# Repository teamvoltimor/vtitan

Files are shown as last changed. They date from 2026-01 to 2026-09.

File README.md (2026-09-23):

# Team Voltimor

> [!NOTE]
> Este repositorio corresponde a nuestra participación en la World Robot Olympiad 2026 con vTitan. Si buscas información sobre nuestra participación en la World Robot Olympiad 2025 con Klevor, el robot del Team Steel Bot, visita el repositorio [**klevor**](https://github.com/teamsteelbot/klevor).

> 🕊️ Este proyecto está dedicado a la memoria de **Javier Pérez** ([@kaucrow](https://github.com/kaucrow)), amigo y colega, y de **Luna Margarita**, compañera de doce años. La [dedicatoria completa](memorial.md) vive en [`memorial.md`](memorial.md).

<p align="center">
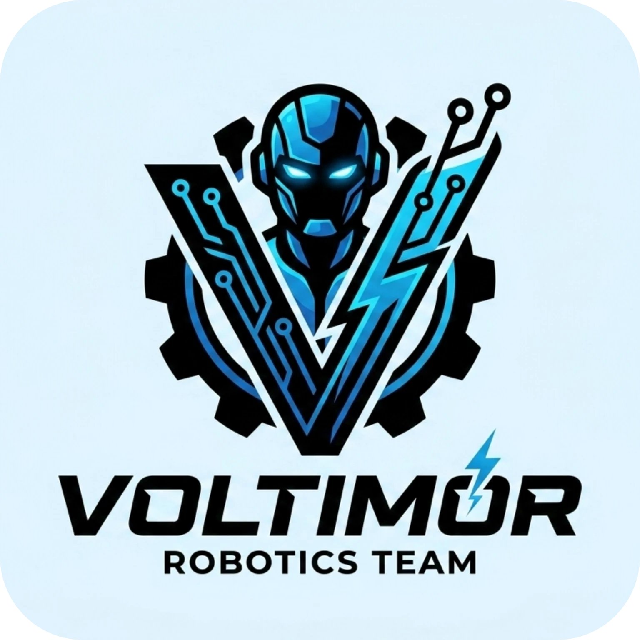
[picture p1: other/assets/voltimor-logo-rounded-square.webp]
Logo del Team Voltimor
    
    <br>
    <i>Logo del Equipo</i>
</p>

Bienvenidos al repositorio de vTitan, el robot del Team Voltimor, que compite en la World Robot Olympiad 2026 en la categoría Futuros Ingenieros. Aquí encontrarás toda la información sobre el robot, incluyendo su código, modelos 3D, esquemas y documentación.

<p align="center">
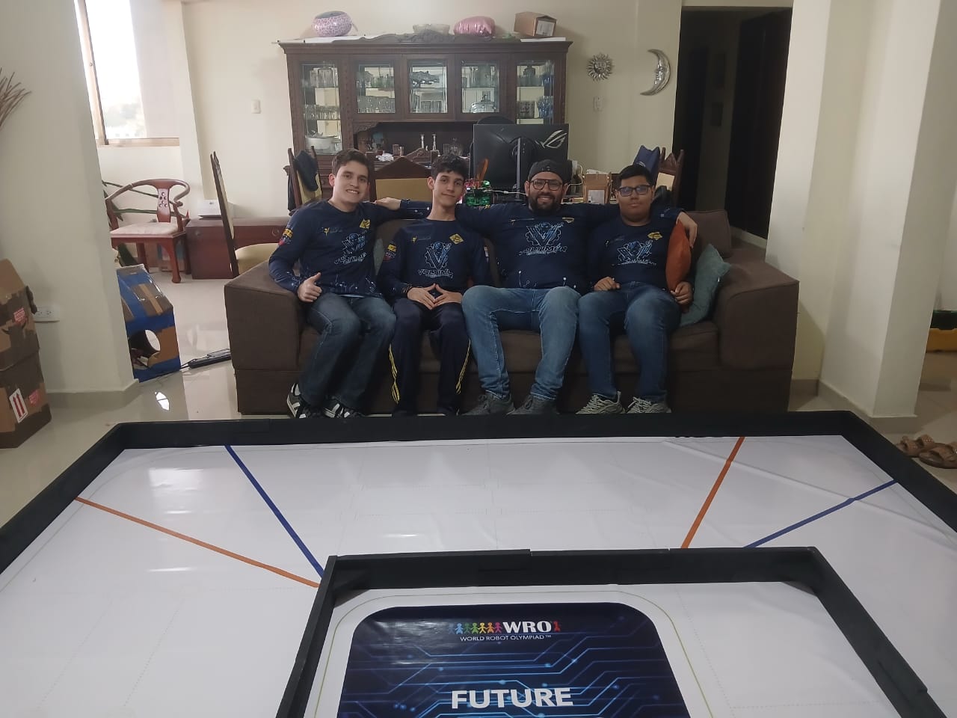
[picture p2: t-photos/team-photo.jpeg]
El equipo de Voltimor con vTitan
    
    <br>
    <i>Foto del Equipo, de izquierda a derecha: Ramón Álvarez, Sebastián Álvarez, Jesús Pérez (Padre, Mentor), Jesús Pérez</i>
</p>

El equipo lo forman tres miembros:

- **Ramón Álvarez**, 20 años. [ralvarezdev](https://github.com/ralvarezdev). Líder del equipo y encargado de la programación. Trabaja en Automation Labs y finalizó sus estudios de Ingeniería en Computación en URU.
- **Sebastián Álvarez**, 16 años. [salvarezdev](https://github.com/salvarezdev). Encargado de la programación, la documentación y las decisiones sobre la lógica del robot. Cursa el primer trimestre de Ingeniería en Computación en URU.
- **Jesús Pérez**, 16 años. [JesusPerez15](https://github.com/JesusPerez15). Encargado del diseño, la mecánica y la fabricación del robot. Cursa quinto año de bachillerato en el Colegio Salto Ángel.

## vTitan en números

<table align="center">
<thead>
<tr>
<th align="left">Métrica</th>
<th align="left">Valor</th>
<th align="left">Contexto</th>
</tr>
</thead>
<tbody>
<tr>
<td align="left">Detección de señales</td>
<td align="left"><strong>15 Hz</strong> punta a punta</td>
<td align="left">Captura 640x640 + inferencia NPU + publicación; 101.5 FPS el modelo solo</td>
</tr>
<tr>
<td align="left">Corpus de simulación</td>
<td align="left"><strong>638 / 640</strong> escenarios Open</td>
<td align="left">Semilla fija y resultados repetibles; los 2 casos restantes identificados uno por uno</td>
</tr>
<tr>
<td align="left">Peso del robot</td>
<td align="left"><strong>~1460 g</strong></td>
<td align="left">Límite reglamentario 1500 g, con ~40 g de margen</td>
</tr>
<tr>
<td align="left">Techo de velocidad real</td>
<td align="left"><strong>~0.58 m/s</strong></td>
<td align="left">Descubierto al corregir un error de cuantización que lo limitaba a 0.45 m/s</td>
</tr>
<tr>
<td align="left">Duración de una ronda</td>
<td align="left"><strong>180 s</strong> sin pausa</td>
<td align="left">Por eso todo lo que ocurre a bordo queda grabado en bags MCAP</td>
</tr>
<tr>
<td align="left">Lazo de velocidad en pista</td>
<td align="left"><strong>~2% de error</strong> de seguimiento</td>
<td align="left">Tres vueltas limpias en 132.5 s frente a 142.3 s antes del ajuste</td>
</tr>
</tbody>
</table>

Cada número es medido, no estimado, y puede rastrearse hasta el código y la medición que lo produjo vía el historial de git (ver [Versionado](#versionado)).

**Índice**

1. **[vTitan en números](#vtitan-en-números)**
2. **[Estructura del repositorio](#estructura-del-repositorio)**
    1. [Cómo explorar este repositorio](#cómo-explorar-este-repositorio)
3. **[Arranque rápido y reproducibilidad](#arranque-rápido-y-reproducibilidad)**
    1. [Requisitos previos](#requisitos-previos-una-sola-vez)
    2. [Desarrollo y simulación](#desarrollo-y-simulación-en-el-computador-de-desarrollo)
    3. [Despliegue al robot](#despliegue-al-robot-desde-el-computador-por-ssh)
    4. [Operación en pista](#operación-en-pista-directamente-en-la-raspberry-pi-5-vía-ssh)
    5. [Provisionado desde cero](#provisionado-desde-cero-instalar-el-sistema-en-las-raspberry-pi)
    6. [Documentación](#documentación)
    7. [Pruebas](#pruebas)
    8. [Versionado](#versionado)
4. **[Historial del equipo](#historial-del-equipo)**
    1. [Klevor (WRO 2025)](#klevor-wro-2025)
        1. [Klevor v0.1](other/docs/development/previous-prototypes/klevor-v0.1.md)
        2. [Klevor v0.1.1](other/docs/development/previous-prototypes/klevor-v0.1.1.md)
        3. [Klevor v0.2](other/docs/development/previous-prototypes/klevor-v0.2.md)
        4. [Klevor v1.0](other/docs/development/previous-prototypes/klevor-v1.0.md)
    2. [vTitan (WRO 2026)](#vtitan-wro-2026)
5. **[Movilidad y diseño mecánico](#movilidad-y-diseño-mecánico)**
    1. [Restricciones iniciales](#restricciones-iniciales)
    2. [Métodos de prototipaje](#métodos-de-prototipaje)
    3. [Evolución y justificación del diseño](#evolución-y-justificación-del-diseño)
        1. [Fase 1: prototipo de rin estático, corona interna y guayas flexibles](#fase-1-prototipo-de-rin-estático-corona-interna-y-guayas-flexibles)
        2. [Fase 2: pruebas de integración y detección de fallas](#fase-2-pruebas-de-integración-y-detección-de-fallas)
        3. [Fase 3: rediseño a engranajes perpendiculares, coronas y correa dentada](#fase-3-rediseño-a-engranajes-perpendiculares-coronas-y-correa-dentada)
        4. [Fase 4: optimización de peso, integración y chasis final](#fase-4-optimización-de-peso-integración-y-chasis-final)
        5. [Fase 5: integración del REV HD Hex Motor](#fase-5-integración-del-rev-hd-hex-motor)
    4. [Sistema de transmisión](#sistema-de-transmisión)
    5. [Sistema de dirección](#sistema-de-dirección)
    6. [Estructura mecánica](#estructura-mecánica)
        1. [Chasis inferior](#chasis-inferior)
        2. [Monochasis](#monochasis)
    7. [Montaje](#montaje)
        1. [Las piezas, y cómo mirarlas](#las-piezas-y-cómo-mirarlas)
    8. [Relación de torque y velocidad](#relación-de-torque-y-velocidad)
        1. [Velocidad: teórica contra real](#velocidad-teórica-contra-real)
6. **[Arquitectura de energía y sensores](#arquitectura-de-energía-y-sensores)**
    1. [Lista de componentes](#lista-de-componentes)
        1. [Raspberry Pi 5 (16 GB de RAM)](#raspberry-pi-5-16-gb-de-ram)
        2. [Raspberry Pi Camera Module 3 Wide](#raspberry-pi-camera-module-3-wide)
        3. [Raspberry Pi AI HAT+ (26 TOPS)](#raspberry-pi-ai-hat-26-tops)
        4. [Raspberry Pi Zero 2 W](#raspberry-pi-zero-2-w)
        5. [RPLiDAR C1](#rplidar-c1)
        6. [Servomotor Hiwonder HPS-3527SG (35 kg·cm)](#servomotor-hiwonder-hps-3527sg-35-kgcm)
        7. [REV HD Hex Motor](#rev-hd-hex-motor)
        8. [IMU GY-BNO085](#imu-gy-bno085)
        9. [Batería Li-Po Ovonic Air de 11.1 V](#batería-li-po-ovonic-air-de-111-v)
        10. [Puente H BTS7960 / IBT-2](#puente-h-bts7960--ibt-2)
        11. [Step Down Mini-560 Pro](#step-down-mini-560-pro)
        12. [Pantalla OLED SSD1306](#pantalla-oled-ssd1306)
        13. [Convertidor KL89576 (DC a USB-C)](#convertidor-kl89576-dc-a-usb-c)
    2. [Diagrama de conexiones](#diagrama-de-conexiones)
    3. [Consumo energético](#consumo-energético)
    4. [Calibración](#calibración)
7. **[Arquitectura de software](#arquitectura-de-software)**
    1. [Arquitectura ROS2 y reparto entre dos computadores](#arquitectura-ros2-y-reparto-entre-dos-computadores)
        1. [La pantalla OLED, el único instrumento en pista](#la-pantalla-oled-el-único-instrumento-en-pista)
        2. [La segunda pila (stack) en Go, y por qué no corre en carrera](#la-segunda-pila-stack-en-go-y-por-qué-no-corre-en-carrera)
    2. [Modelo de detección YOLO](#modelo-de-detección-yolo)
        1. [El modelo y su cadena de procesamiento](#el-modelo-y-su-cadena-de-procesamiento)
        2. [Datos de entrenamiento](#datos-de-entrenamiento)
        3. [Cómo lo medimos (y qué cambió por eso)](#cómo-lo-medimos-y-qué-cambió-por-eso)
        4. [Qué pasa cuando la visión falla](#qué-pasa-cuando-la-visión-falla)
    3. [Algoritmo PID](#algoritmo-pid)
        1. [Control de velocidad: PI sobre RPM](#control-de-velocidad-pi-sobre-rpm)
        2. [Dirección: de PID a pure pursuit](#dirección-de-pid-a-pure-pursuit)
        3. [El modo ciego: P de centrado eliminada por medición](#el-modo-ciego-p-de-centrado-eliminada-por-medición)
        4. [El rol del giroscopio](#el-rol-del-giroscopio)
8. **[Estrategia en pista](#estrategia-en-pista)**
    1. [Inferencia del sentido de la vuelta](#inferencia-del-sentido-de-la-vuelta)
    2. [Seguimiento de pasillo, vueltas y escapes](#seguimiento-de-pasillo-vueltas-y-escapes)
    3. [Vista completa de cada desafío](#vista-completa-de-cada-desafío)
9. **[Análisis y simulación](#análisis-y-simulación)**
    1. [Grabación y análisis de carreras](#grabación-y-análisis-de-carreras)
    2. [Simulador y corpus de escenarios](#simulador-y-corpus-de-escenarios)
10. **[Pensamiento sistémico y decisiones de ingeniería](#pensamiento-sistémico-y-decisiones-de-ingeniería)**
    1. [Interacciones entre subsistemas](#interacciones-entre-subsistemas)
    2. [Diseño gobernado por configuración](#diseño-gobernado-por-configuración)
    3. [Perfiles de hardware intercambiables](#perfiles-de-hardware-intercambiables)
    4. [Compensaciones y alternativas descartadas](#compensaciones-y-alternativas-descartadas)
    5. [Registro de decisiones de arquitectura (ADR)](#registro-de-decisiones-de-arquitectura-adr)
    6. [Ciclo de trabajo: idea → simulación → pista](#ciclo-de-trabajo-idea--simulación--pista)
    7. [Hallazgos de ingeniería](#hallazgos-de-ingeniería)
    8. [Gestión de riesgos](#gestión-de-riesgos)
    9. [Tecnologías utilizadas](#tecnologías-utilizadas)
11. **[Videos de vTitan](#videos-de-vtitan)**
    1. [Open Challenge](#open-challenge)
    2. [Open Challenge Simulation](#open-challenge-simulation)
    3. [Obstacle Challenge Simulation](#obstacle-challenge-simulation)
    4. [Parking Challenge](#parking-challenge)
    5. [Otros](#otros)

## Estructura del repositorio

La raíz del repositorio sigue la estructura que pide la categoría Futuros Ingenieros de la WRO. Cada carpeta obligatoria está en su sitio, y las que apuntan a un monorepo más grande llevan su propio `README.md` con la ruta exacta:

```text
vtitan/
├── README.md          # Este documento: la documentación completa de ingeniería
├── CHANGELOG.md       # Notas de versión de v1.0, v1.1 y v1.2
├── t-photos/          # Fotos del equipo
├── v-photos/          # Fotos de vTitan y de los prototipos anteriores
├── video/             # Enlaces a los videos de las rondas (video/video.md)
├── schemes/           # Diagramas de flujo y esquemático de conexiones
│   ├── flowcharts/    #   Fuentes Mermaid + renders WebP: common/, open/, obstacles/
│   └── wiring/        #   Esquemático del arnés + proyecto tscircuit que lo genera
├── models/            # Modelos 3D (ver models/README.md)
│   ├── vtitan/      #   WRO 2026: blueprints/, step-files/ (CAD), stl-files/ (visor 3D)
│   └── klevor/      #   WRO 2025: el prototipo de la temporada anterior
├── src/               # python/ (pila ROS2), go/ (reimplementación Go), config/ (TOML
│                      #   compartido, leído por ambos), model/ (esquemas JSON que
│                      #   validan ese TOML), tools/ y assets/ (imágenes compartidas)
├── other/             # Todo lo que no es material de competencia
│   ├── apps/          #   backend/, frontend/, gazebo/, auto-annotator/, hugo-docs/, landing/
│   ├── assets/        #   Logos e imágenes de esta documentación
│   ├── contracts/     #   proto/ (buf, esquemas gRPC/NATS) y openapi/ (spec-first REST)
│   ├── data/          #   Salidas de ejecución (bags, fotos, videos); vacía en el repo
│   ├── deploy/ansible/#   Provisionamiento de las placas (tareas task rpi:*, windows:*)
│   ├── docs/          #   Bitácora, referencia de configuración, datasheets, prototipos
│   ├── ml/hailo/ ml/weights/  # Entrenamiento del detector y pesos publicados
│   ├── scripts/       #   Utilidades de desarrollo (configuración de SSH para el robot)
│   └── tasks/         #   Tareas del Taskfile raíz (fleet.yml, platform.yml, infra.yml)
└── .github/           # Flujos de trabajo de CI
```

<table align="center">
<thead>
<tr>
<th align="left">Carpeta</th>
<th align="left">Contenido</th>
</tr>
</thead>
<tbody>
<tr>
<td align="left"><code>README.md</code></td>
<td align="left">Este documento: la documentación completa de ingeniería de vTitan</td>
</tr>
<tr>
<td align="left"><code>other/docs/tests.md</code></td>
<td align="left">El flujo de pruebas: los cuatro niveles, las métricas y el protocolo de comparación A/B</td>
</tr>
<tr>
<td align="left"><code>CHANGELOG.md</code></td>
<td align="left">Notas de versión: qué cambió en <code>v1.0</code>, <code>v1.1</code> y <code>v1.2</code>, y por qué</td>
</tr>
<tr>
<td align="left"><code>t-photos/</code></td>
<td align="left">Fotos del equipo</td>
</tr>
<tr>
<td align="left"><code>v-photos/</code></td>
<td align="left">Fotos de vTitan y de los prototipos anteriores</td>
</tr>
<tr>
<td align="left"><code>video/</code></td>
<td align="left">Enlaces a los videos de las rondas y del robot en funcionamiento (<a href="video/video.md"><code>video/video.md</code></a>)</td>
</tr>
<tr>
<td align="left"><code>schemes/</code></td>
<td align="left">Diagramas de flujo y esquemático de conexiones. En <code>schemes/flowcharts/</code> están las fuentes Mermaid y sus renders WebP, separados en <code>common/</code> (lógica compartida por ambos desafíos), <code>open/</code> y <code>obstacles/</code>; <code>schemes/flowcharts/_legacy/</code> conserva los diagramas de versiones anteriores. En <code>schemes/wiring/</code> está el esquemático del arnés junto al proyecto tscircuit que lo genera</td>
</tr>
<tr>
<td align="left"><code>models/</code></td>
<td align="left">Modelos 3D de las piezas, una carpeta por robot: <code>vtitan/</code> (WRO 2026) y <code>klevor/</code> (WRO 2025), cada una con <code>blueprints/</code> (planos), <code>step-files/</code> (CAD para fabricar y editar) y <code>stl-files/</code> (para imprimir, y que <strong>GitHub renderiza en un visor 3D interactivo</strong>). Inventario completo en <a href="models/README.md"><code>models/README.md</code></a></td>
</tr>
<tr>
<td align="left"><code>src/</code></td>
<td align="left">El código de competencia y lo que comparte con la segunda implementación en Go: <code>src/python/</code> (pila ROS2, ver <a href="src/python/README.md"><code>src/python/README.md</code></a>), <code>src/go/</code> (reimplementación Go), <code>src/config/</code> (TOML que ambos leen), <code>src/model/</code> (los esquemas JSON que validan ese TOML y apuntan a su ADR), <code>src/tools/</code> y <code>src/assets/</code> (imágenes compartidas, p. ej. el logo del HUD).</td>
</tr>
<tr>
<td align="left"><code>other/</code></td>
<td align="left">Todo lo que no es material de competencia: <code>other/apps/</code> (telemetría, simulador, auto-anotador, docs), <code>other/contracts/</code> (proto + OpenAPI compartidos), <code>other/ml/</code> (entrenamiento y pesos), <code>other/deploy/ansible/</code>, <code>other/docs/</code>, <code>other/data/</code>, <code>other/scripts/</code>, <code>other/tasks/</code> y <code>other/assets/</code>. Ver <a href="other/README.md"><code>other/README.md</code></a></td>
</tr>
</tbody>
</table>

### Cómo explorar este repositorio

Según lo que quieras revisar, esta es la ruta más corta:

- **Código que corre en una ronda**: [`src/python/README.md`](src/python/README.md) mapea cada nodo ROS2 de la pila de competencia a su paquete y su rol (percepción, navegación, máquina de estados, drivers).
- **Configuración que gobierna al robot**: `src/config/`, descrita en [Diseño gobernado por configuración](#diseño-gobernado-por-configuración). Los perfiles de hardware intercambiables están en [Perfiles de hardware intercambiables](#perfiles-de-hardware-intercambiables). La lee tanto `src/python/` como `src/go/`.
- **Simulador y corpus de escenarios**: [`other/README.md`](other/README.md), sección del simulador; los resultados reproducibles están en [Simulador y corpus de escenarios](#simulador-y-corpus-de-escenarios).
- **Cómo se entrenó el detector**: `other/ml/hailo/` (entrenamiento y compilación), `other/ml/weights/` (pesos publicados), `other/apps/auto-annotator/` (anotación asistida).
- **Cómo se instala el sistema en las placas**: [`other/docs/pi-setup.md`](other/docs/pi-setup.md) y `other/deploy/ansible/`; automatizado por los comandos `task rpi:provision:*` de [Arranque rápido](#arranque-rápido-y-reproducibilidad).
- **Las piezas del robot en 3D**: [`models/README.md`](models/README.md). Los `.stl` se abren directamente en el visor 3D de GitHub, sin instalar nada. Los diagramas y el arnés, en [`schemes/README.md`](schemes/README.md); las vistas del robot, en [`v-photos/README.md`](v-photos/README.md).
- **Cómo verificamos que algo funciona**: [`other/docs/tests.md`](other/docs/tests.md), que describe los cuatro niveles de prueba y el protocolo con el que aceptamos o descartamos un cambio.
- **El historial del proyecto**: bitácora de ingeniería en [`other/docs/bitacora-ingenieria.md`](other/docs/bitacora-ingenieria.md), prototipos previos en [`other/docs/development/previous-prototypes/`](other/docs/development/previous-prototypes/klevor-v0.1.md), y las etiquetas de git (`v1.0` regional, `v1.1` y `v1.2` posteriores) con mensajes de commit convencionales.

Además de las carpetas obligatorias, el repositorio contiene:

- `src/` con el código: `src/python/` (la pila ROS2 de competencia), `src/go/` (la segunda implementación en Go), `src/config/` (la configuración TOML que ambos leen), `src/model/` (los esquemas JSON que la validan y la enlazan con su ADR), `src/tools/` y `src/assets/` (imágenes compartidas, p. ej. el logo del HUD de navegación).
- `other/contracts/` con los contratos de interfaz que generan código para los tres consumidores (robot, backend y frontend): `other/contracts/proto/` (buf, esquemas gRPC/NATS) y `other/contracts/openapi/` (spec-first REST).
- `other/docs/` con la documentación de apoyo: la [bitácora de ingeniería](other/docs/bitacora-ingenieria.md), la [referencia de configuración TOML de navegación](other/docs/configuracion-toml-navegacion.md), la [guía de instalación de las Raspberry Pi](other/docs/pi-setup.md), las hojas de datos en `other/docs/reference/datasheets/` y el historial de prototipos en `other/docs/development/previous-prototypes/`.
- `other/apps/` con procesos independientes: `other/apps/backend/` y `other/apps/frontend/` (telemetría), `other/apps/auto-annotator/` (anotación asistida), `other/apps/hugo-docs/` (sitio de documentación navegable), `other/apps/gazebo/` (entorno de ejecución del simulador) y `other/apps/landing/` (página de presentación).
- `other/ml/hailo/` con el entrenamiento y la compilación del detector YOLO, `other/ml/weights/` con los pesos publicados.
- `other/deploy/ansible/` con el provisionamiento de las placas; las tareas que lo ejecutan (`task rpi:*`, `task windows:provision:*`) están definidas en `other/tasks/fleet.yml`.
- `other/scripts/` con utilidades de desarrollo (configuración de SSH para el robot) y `.github/` con los flujos de trabajo de CI.
- `other/data/` es la carpeta de salida en tiempo de ejecución: `other/data/live/` y `other/data/sim/` guardan los bags, fotos y videos que producen las corridas del robot y del simulador. En el repositorio solo está su estructura (archivos `.gitkeep`); el contenido se llena al ejecutar `task robot:pull-runs` (bags desde la Pi 5), `task robot:pull-videos` (videos por ronda) o las corridas de simulación, y no se versiona.

## Arranque rápido y reproducibilidad

Todo el ciclo de vida del proyecto, desde la simulación y las pruebas hasta el despliegue al robot y la operación en pista, está automatizado con [Task](https://taskfile.dev) (Taskfile) y [Pixi](https://pixi.sh) / [uv](https://docs.astral.sh/uv/). Todo se invoca con `task`; la CLI `vt` (ver más abajo) ayuda a descubrir y lanzar esos mismos comandos. Nada de lo que hacemos depende de pasos manuales no documentados: otra persona puede clonar el repositorio y llegar del código al robot con estos comandos.

### Requisitos previos (una sola vez)

- [Task](https://taskfile.dev) (`go install github.com/go-task/task/v3/cmd/task@latest` o el instalador de la página)
- [uv](https://docs.astral.sh/uv/) (entornos de Python fuera de ROS2: herramientas y scripts de apoyo)
- [Pixi](https://pixi.sh) (gestiona los entornos de Python + ROS2 en el robot y la simulación)
- [Go](https://go.dev) 1.26+ (backend de telemetría, generador de escenarios y binarios del robot)
- Node.js 22+ (dashboard, el panel de telemetría)

### Desarrollo y simulación (en el computador de desarrollo)

```bash
task install          # Dependencias de simulación, robot y backend Go
task init:dev         # Configuración completa: install + lint

# Generar la pista y el corpus de escenarios (semilla fija → resultados repetibles)
task gen:corpus:all   # 640 escenarios Open + 256 Obstacle, semilla 2026

# Visualizar en RViz una carrera a lazo cerrado (simulador de navegación)
task sim:navigate:visualize:all -- --challenge open --interactive

# Pruebas: todas, o por subsistema
task test             # Python + Go, todos los módulos (ver Pruebas, más abajo)
```

### CLI de desarrollo `vt` (opcional)

`vt` es una capa sobre los mismos Taskfiles: organiza las tareas en subcomandos agrupados, les da flags tipados y ejecuta `task` por debajo, devolviendo su mismo código de salida. `task X` sigue funcionando exactamente igual y es lo que usa CI; `vt` solo existe en el computador de desarrollo, las placas siguen con `task`. Los comandos que solo existen en Windows (enlace Ethernet directo, rutas) se ocultan en Linux y macOS.

La regla de reparto es **los Taskfiles deciden qué se ejecuta, `vt` decide cómo se escribe**: un cambio que altere lo que hace una tarea va en el Taskfile (y así lo heredan `task` y CI); uno que cambie cómo se descubre, se parametriza o se confirma va en `vt`. Hoy son ~160 comandos tipados sobre 19 dominios, y cualquier tarea sigue alcanzable por `vt task`.

Dominios (`vt --help`, el menú y el selector usan el mismo orden): robot y simulación `sim`, `robot`, `go`, `fleet`, `gen`; las apps `frontend`, `backend`, `annotator`, `hailo`; contratos y modelos `config`, `proto`, `openapi`, `models`; transversales `setup`, `test`, `lint`, `clean`, `workflow`, `docker`, `docs`; y herramientas `cli`, `simgen`, `shared`. Dentro de cada dominio el orden es siempre el mismo: ejecutar (`dev`, `build`), luego calidad (`test`, `lint`, `typecheck`, `fmt`) y al final instalación y limpieza.

```bash
task cli:build                      # Compila src/go/bin/vt (recomendado)
task cli:run -- sim --help          # O sin compilar, vía go run

src/go/bin/vt                       # En una terminal: selector con los últimos comandos arriba; la salida se ve dentro y se vuelve al menú
src/go/bin/vt sim view -- --challenge open --interactive   # Simulador + RViz en un solo comando
src/go/bin/vt gen corpus --both     # Corpus de barrido de ambos desafíos (semilla fija)
src/go/bin/vt fleet set-wifi zero --ssid Casa --password '...'
src/go/bin/vt lint --fix            # Las variantes de una tarea son flags, no subcomandos
src/go/bin/vt --dry-run robot deploy   # Muestra la línea de task que ejecutaría, sin ejecutar nada
src/go/bin/vt task                  # Todas las tareas con su descripción
src/go/bin/vt task gen:track        # Cualquier tarea, con o sin flags tipados
src/go/bin/vt cli test              # vt se prueba a sí mismo (los checks anti-drift)
src/go/bin/vt annotator ml test     # Suite del servicio de ML del auto-annotator
src/go/bin/vt docs check            # Falla si la prosa apunta a rutas que ya no existen
source <(src/go/bin/vt completion bash)   # Autocompletado (también zsh y fish)
```

### Despliegue al robot (desde el computador, por SSH)

```bash
task robot:deploy         # Código + detector HEF → recompilar colcon → reiniciar servicios
task robot:watch-vision   # Detecciones en vivo, una línea por fotograma
task robot:pull-runs      # Descargar los bags MCAP de las carreras
```

### Operación en pista (directamente en la Raspberry Pi 5, vía SSH)

```bash
task rpi:stack ACTION=up           # Levantar la pila de servicios en el orden correcto
task rpi:stack ACTION=status       # Estado de la pila
task rpi:stack ACTION=logs         # Últimos registros de todos los servicios
task rpi:health                    # Captura de salud: temperatura, throttling, disco, RAM
task robot:calibrate-encoder       # Calibración de pulsos/vuelta contra distancia medida
task robot:test-motors             # Prueba de humo de hardware: rango de servo + pulso de motor
```

### Provisionado desde cero (instalar el sistema en las Raspberry Pi)

```bash
task windows:provision:pi5         # Provisionar la Pi 5 con Ansible (etiquetas opcionales)
task rpi:provision:all             # Ambas placas, en tmux, tras regrabar la SD
task rpi:ansible:check BOARD=pi5   # Ensayo en seco y diferencias del provisionador
```

### Documentación

```bash
task docs:diagrams                 # Re-renderizar todos los diagramas Mermaid a WebP
cd schemes/wiring/tscircuit && npm run artifacts   # Regenerar el esquemático del arnés
```

### Pruebas

```bash
task test                      # Python + Go, todos los módulos
task robot:test SCOPE=unit     # unit | navigation | hardware | all
task sim:test                  # pruebas de la simulación
task config:check              # cada clave de configuración descrita y con su ADR
task lint                      # ruff, golangci-lint, ESLint, buf lint
```

El **flujo de pruebas completo** está documentado en [`other/docs/tests.md`](other/docs/tests.md): los cuatro niveles (unitario, corpus de simulación, banco de hardware, pista), las métricas con las que decidimos, el protocolo de comparación A/B con las cinco trampas que nos costaron conclusiones falsas, y el estado real de la integración continua.

### Versionado

Marcamos hitos del proyecto con etiquetas de git. `v1.0` es el estado con el que vTitan compitió en el evento regional de la WRO 2026; `v1.1` y `v1.2` son los estados posteriores que se desplegaron y corrieron rondas. Las notas de cada versión, con qué cambió y por qué, están en [`CHANGELOG.md`](CHANGELOG.md).

Entre etiquetas el historial es continuo, con mensajes de commit convencionales (`fix(robot):`, `docs(readme):`, `perf(nav):`) y firmados con GPG. Cualquier resultado medido en este documento (tasas del corpus, FPS del detector, consumo de potencia) puede rastrearse hasta el código exacto que lo produjo vía el historial.

Un detalle de convención que usamos y no es estándar: el `!` en el tipo (`feat(sim)!:`) marca un cambio que **rompe la comparabilidad de resultados anteriores**, no solo la compatibilidad de una interfaz. Un número medido antes de uno de esos commits no se resta con uno medido después.

## Historial del equipo

Aquí repasamos nuestras temporadas anteriores en Futuros Ingenieros y lo que aprendimos de los prototipos que precedieron a vTitan.

### Klevor (WRO 2025)

<details>
<summary><b>Vistas de Klevor (seis vistas)</b></summary>

<table align="center">
        <tbody>
                <tr>
                        <td>
                                <p align="center">
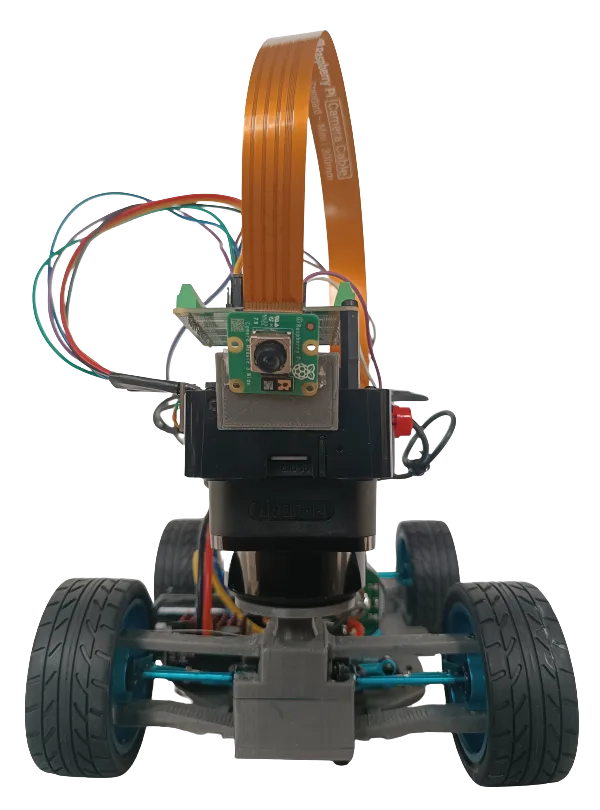
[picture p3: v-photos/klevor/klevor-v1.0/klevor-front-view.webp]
Vista delantera de Klevor
                                        
                                        <br>
                                        <i>Vista delantera de Klevor</i>
                                </p>
                        </td>
                        <td>
                                <p align="center">
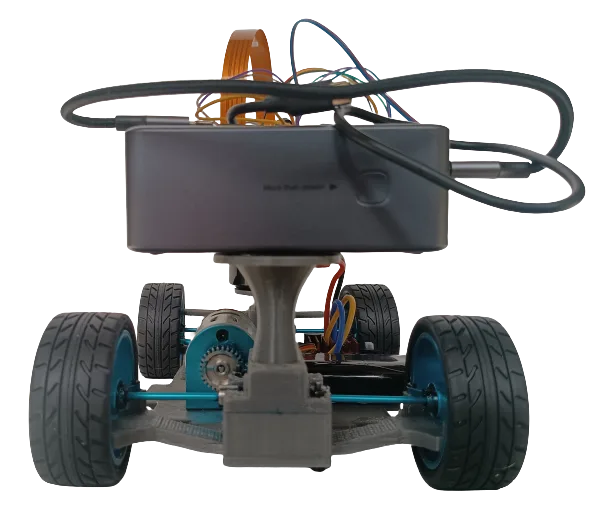
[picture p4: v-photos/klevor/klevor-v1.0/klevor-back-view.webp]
Vista trasera de Klevor
                                        
                                        <br>
                                        <i>Vista trasera de Klevor</i>
                                </p>
                        </td>
                </tr>
                <tr>
                        <td>
                                <p align="center">
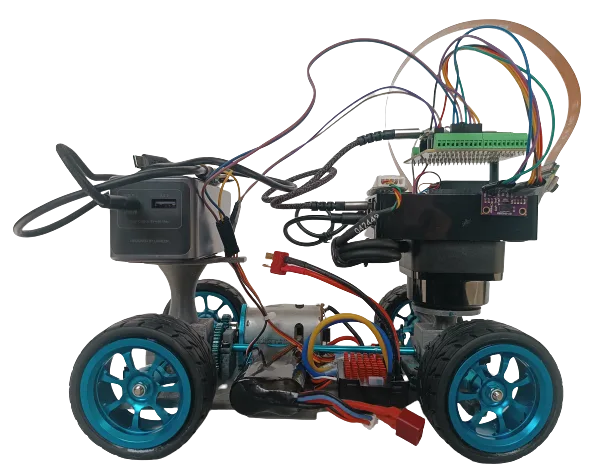
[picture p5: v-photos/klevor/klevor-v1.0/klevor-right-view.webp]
Vista derecha de Klevor
                                        
                                        <br>
                                        <i>Vista derecha de Klevor</i>
                                </p>
                        </td>
                        <td>
                                <p align="center">
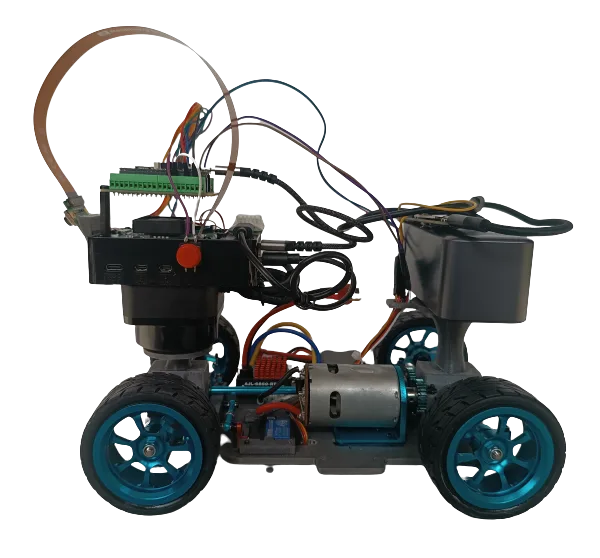
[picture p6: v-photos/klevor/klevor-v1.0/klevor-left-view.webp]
Vista izquierda de Klevor
                                        
                                        <br>
                                        <i>Vista izquierda de Klevor</i>
                                </p>
                        </td>
                </tr>
                <tr>
                        <td>
                                <p align="center">
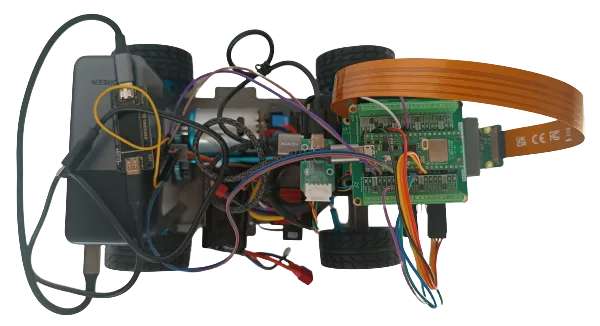
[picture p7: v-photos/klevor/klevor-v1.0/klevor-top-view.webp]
Vista superior de Klevor
                                        
                                        <br>
                                        <i>Vista superior de Klevor</i>
                                </p>
                        </td>
                        <td>
                                <p align="center">
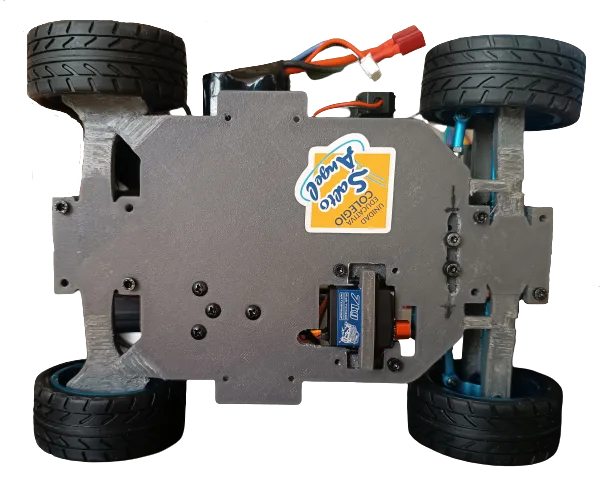
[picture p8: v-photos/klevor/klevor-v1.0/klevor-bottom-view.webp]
Vista inferior de Klevor
                                        
                                        <br>
                                        <i>Vista inferior de Klevor</i>
                                </p>
                        </td>
                </tr>
        </tbody>
</table>

</details>

Klevor es el **predecesor** de vTitan, participando en la temporada 2025 de la World Robot Olympiad en la categoría de Futuros Ingenieros, con el Team Steel Bot (quienes ahora participan bajo el nombre de Team Voltimor) y como todo proyecto fue evolucionando hasta culminar con la versión que tenemos hoy en día. 

Para conocer a nuestro prototipo actual, vTitan, mejor, es importante recalcar que muchas de sus características, más específicamente en la electrónica y programación, son **directamente heredadas** de Klevor, con cambios nulos o mínimos entre un prototipo o el otro. Algunas de las **herencias** más importantes son:

- El manejo de la Raspberry Pi 5 como computadora principal

- La detección de los obstáculos gracias a la Raspberry Pi Camera 3 y su Hailo AI+

- La comunicación serial entre una computadora principal y un microcontrolador

Ahora bien, también hay que recalcar que tuvimos algunos fallos en el desarrollo de Klevor, por ejemplo: 

El uso de un ESC para controlar el motor parecía una idea muy buena en papel: aprovechar el «combo» de motor 540 y variador de un carro de radiocontrol nos daba velocidad de sobra para completar los desafíos. Terminó siendo un problema grave por su falta de precisión: aceleraba demasiado rápido y no había forma de compensarlo desde la programación.

<p align="center">
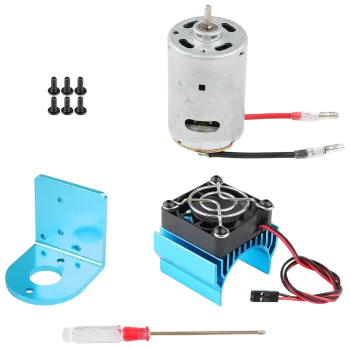
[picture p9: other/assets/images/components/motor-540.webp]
Motor 540 de Klevor
	
	<br>
	<i>El motor 540 de Klevor, heredado de un carro de radiocontrol junto a su variador</i>
</p>

Además, optamos por un modelo más robusto y pesado en comparación con los demás prototipos habituales de esta competición, si bien, gracias a esto pudimos incorporar muchos elementos de gran utilidad (como la Raspberry Pi 5), debido a esto, no podíamos optar por cambios significativos, siendo obligados a reestructurar el prototipo desde cero en caso de necesitar algún cambio.

Debido a la gran cantidad de cambios que necesitamos, por diferentes motivos, teníamos que reestructurar el prototipo múltiples veces, por lo que terminamos confiando ciegamente en algunas características que no pudimos probar completamente.

### vTitan (WRO 2026)

<details>
<summary><b>Vistas de vTitan (seis vistas)</b></summary>

<table align="center">
        <tbody>
                <tr>
                        <td>
                                <p align="center">
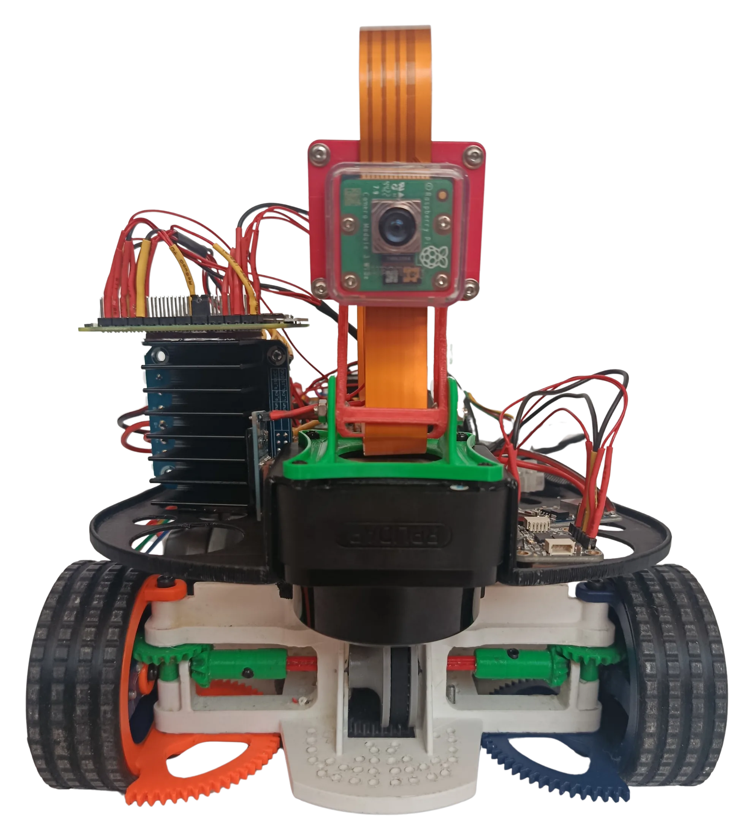
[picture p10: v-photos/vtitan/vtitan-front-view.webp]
Vista delantera de vTitan
                                        
                                        <br>
                                        <i>Vista delantera de vTitan</i>
                                </p>
                        </td>
                        <td>
                                <p align="center">
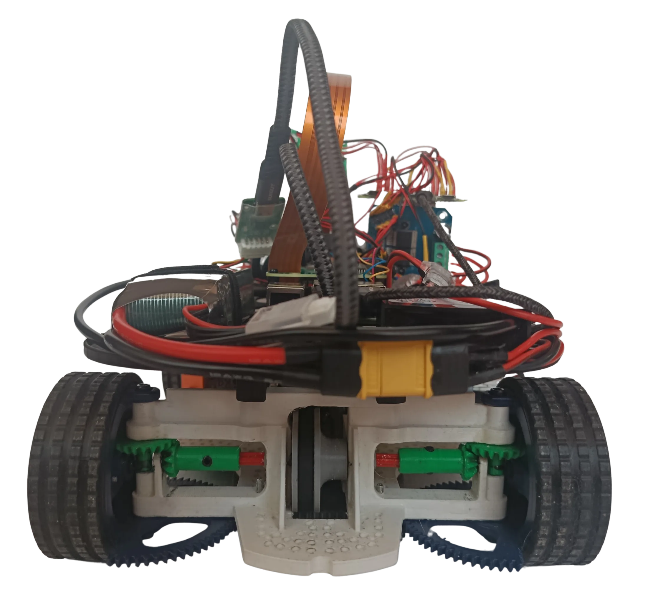
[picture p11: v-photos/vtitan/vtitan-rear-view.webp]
Vista trasera de vTitan
                                        
                                        <br>
                                        <i>Vista trasera de vTitan</i>
                                </p>
                        </td>
                </tr>
                <tr>
                        <td>
                                <p align="center">
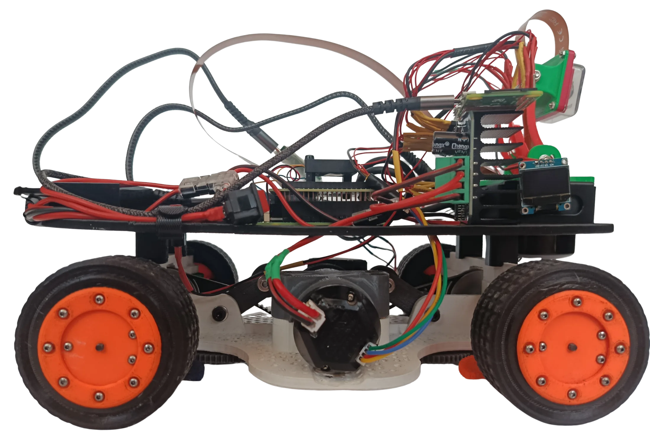
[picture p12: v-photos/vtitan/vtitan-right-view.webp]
Vista derecha de vTitan
                                        
                                        <br>
                                        <i>Vista derecha de vTitan</i>
                                </p>
                        </td>
                        <td>
                                <p align="center">
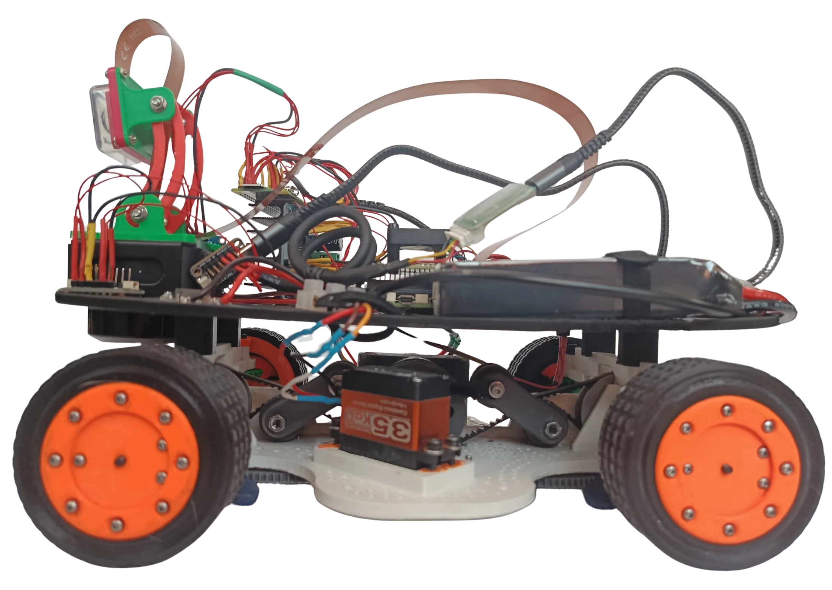
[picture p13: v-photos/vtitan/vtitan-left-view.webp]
Vista izquierda de vTitan
                                        
                                        <br>
                                        <i>Vista izquierda de vTitan</i>
                                </p>
                        </td>
                </tr>
                <tr>
                        <td>
                                <p align="center">
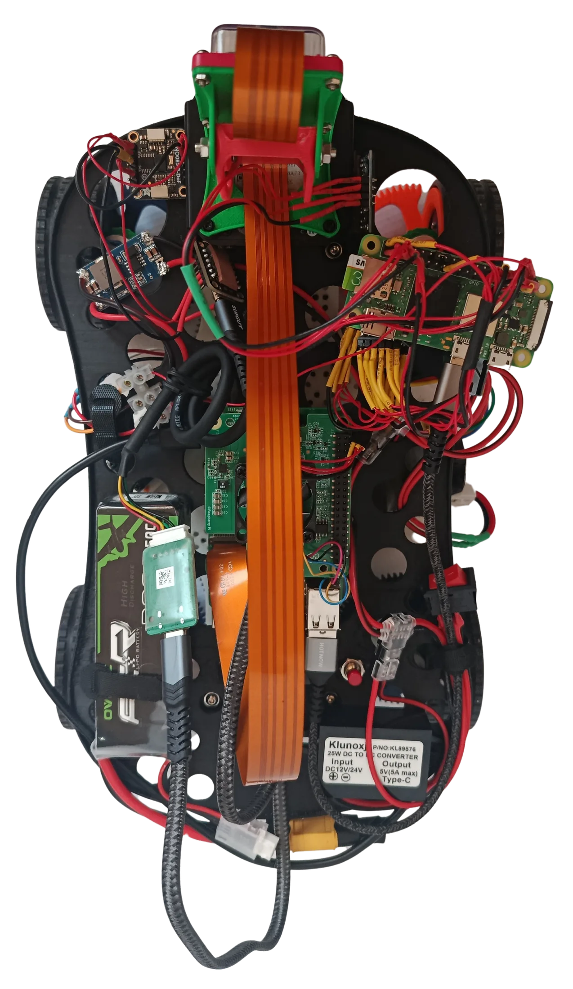
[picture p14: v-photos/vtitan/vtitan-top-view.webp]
Vista superior de vTitan
                                        
                                        <br>
                                        <i>Vista superior de vTitan</i>
                                </p>
                        </td>
                        <td>
                                <p align="center">
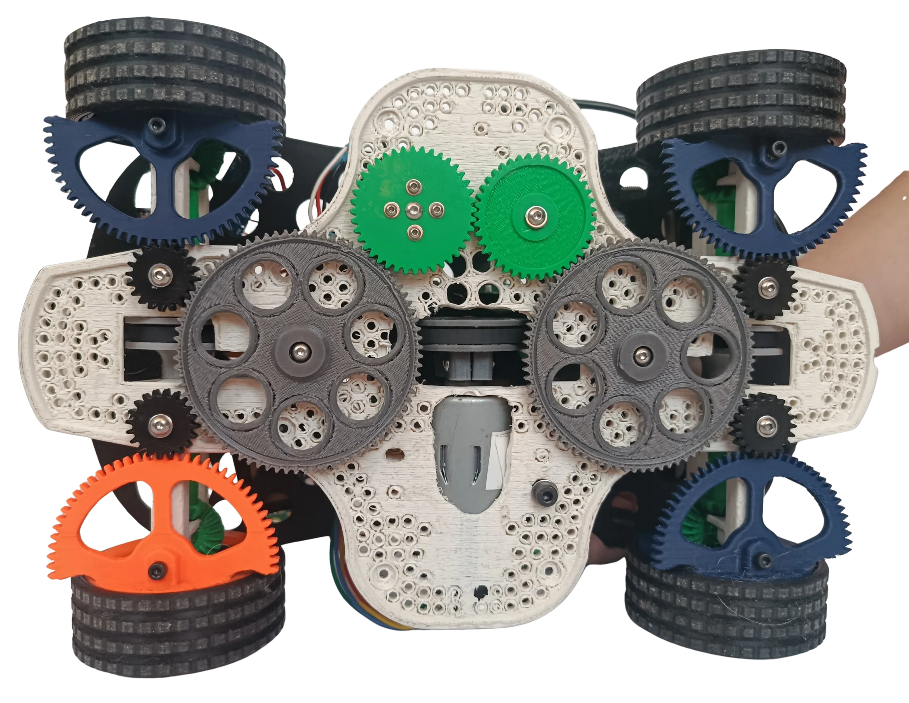
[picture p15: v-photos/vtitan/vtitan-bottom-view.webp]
Vista inferior de vTitan
                                        
                                        <br>
                                        <i>Vista inferior de vTitan</i>
                                </p>
                        </td>
                </tr>
        </tbody>
</table>

</details>

vTitan es el **sucesor** de Klevor, participando en la temporada 2026 de la World Robot Olympiad en la categoría Futuros Ingenieros, con el Team Voltimor (anteriormente Team Steel Bot), y es un proyecto que se encuentra evolucionando hasta el día de hoy.

vTitan mejora en muchos aspectos con respecto a su predecesor, Klevor, con la mayoría de cambios siendo en el aspecto mecánico, ya que, una de nuestras metas principales era implementar un sistema de giro que permita el giro en 90 grados (o lo más cercano posible) para facilitar la estrategia para completar el Obstacle Challenge, además de esto, vTitan conserva muchos de los componentes electrónicos que utilizó Klevor, tales como la Raspberry Pi 5, y el RPLiDAR C1.

## Movilidad y diseño mecánico

Esta sección cubre la movilidad y el diseño mecánico: las restricciones de partida, cómo prototipamos, y la evolución del chasis, la transmisión y la dirección hasta su forma actual.

### Restricciones iniciales

* **Dimensiones y peso límite:** Máximo 300 mm (largo) 200 mm (ancho) 300 mm (alto) y un peso no mayor a 1500 g.

* **Reglamento de tracción y dirección:** Permitido tracción 4x4 impulsada por un **único motor** (o dos conectados en el mismo árbol de transmisión) y sistema de dirección para las 4 ruedas accionado por un **único servomotor**.

### Métodos de prototipaje

Para realizar nuestros prototipos, decidimos utilizar la impresión 3D como método principal, ya que ya éramos bastante familiares con todo el proceso, si bien el uso de máquinas CNC puede ser beneficioso para prototipos de esta categoría, decidimos optar por piezas pre-fabricadas o impresas en 3D, ya que nos permite minimizar el peso de vTitan, ya que el peso fue un problema recurrente en nuestros primeros prototipos, llegando a estar 200 gramos por encima del límite establecido.

Para poder diseñar e imprimir dichas piezas, utilizamos el programa de diseño 3D SolidWorks, ya que tiene una gran cantidad de funciones útiles para el diseño de prototipos mecánicos, y, era el programa con el que teníamos mejor afinidad.

### Evolución y justificación del diseño

Con las reglas claras, la idea rectora para elegir componentes fue la simplicidad: cubrir la mayor cantidad de funciones en pista con la menor cantidad de piezas. De ahí salió esta lista:

- **Navegación**: el [RPLiDAR C1](#rplidar-c1) delimita las paredes de la pista, y el [giroscopio BNO085](#imu-gy-bno085) aporta la orientación, que es lo que da autonomía en los cruces.
- **Percepción de obstáculos**: la [Raspberry Pi Camera Module 3 Wide](#raspberry-pi-camera-module-3-wide) por su campo de visión amplio, con la [Raspberry Pi 5](#raspberry-pi-5-16-gb-de-ram) y el [Raspberry Pi AI HAT+ (26 TOPS)](#raspberry-pi-ai-hat-26-tops) ejecutando el modelo de detección.
- **Actuación**: la [Raspberry Pi Zero 2 W](#raspberry-pi-zero-2-w) como controlador dedicado del [motor](#rev-hd-hex-motor) y el [servomotor](#servomotor-hiwonder-hps-3527sg-35-kgcm).
- **Energía**: la [batería](#batería-li-po-ovonic-air-de-111-v) y el convertidor a 5 V DC que alimenta la Raspberry Pi 5.

Con todos estos componentes en mente, queríamos implementar esta idea en un sistema de transmisión 4x4 con un sistema de dirección que permita generar el giro de 90 grados (o lo más cercano posible) hacia cualquier lado (izquierda o derecha) para permitir que la salida del estacionamiento en el Obstacle Challenge sea lo más fácil posible de programar, además de, cumplir con todas las reglas que tiene esta categoría, a través de pruebas y diseños, para efectos de esta documentación dividimos el proceso en cinco fases:

#### Fase 1: prototipo de rin estático, corona interna y guayas flexibles

<p align="center">
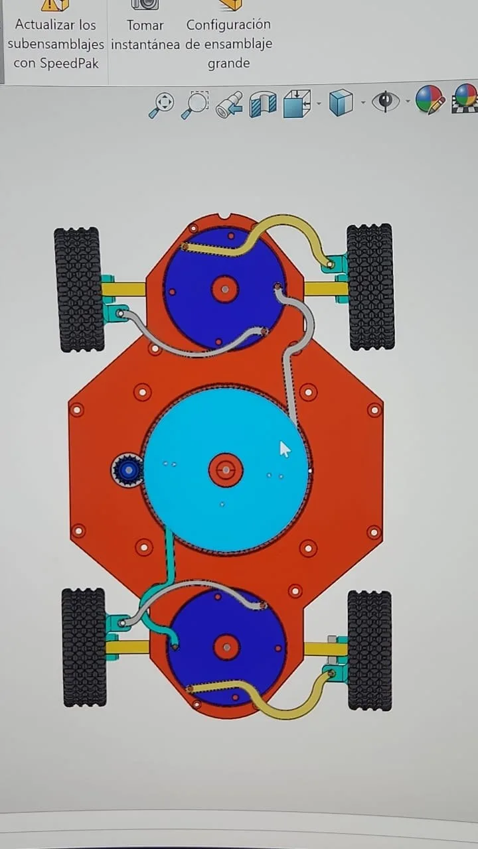
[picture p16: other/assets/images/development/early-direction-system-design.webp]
	
	<br>
	<i>Primer Prototipo del Sistema de Dirección</i>
</p>

* **Mecanismo de Rueda:** Nuestro primer prototipo fue un rin estático (es decir, la rueda sin el caucho exterior) que actúa como soporte/pivote en la tijera, mientras que el caucho exterior móvil incorpora una corona/cremallera interna accionada por piñones para transmitir tracción.

* **Transmisión de Dirección/Potencia:** Se implementaron **guayas flexibles** (cables de transmisión, tipo mototool/rotamil) para llevar el movimiento de rotación a la rueda soportando el ángulo extremo de 90 grados.

* **Caja de Engranajes Modular:** Diseñada para distribuir el movimiento de un solo motor hacia 4 guayas independientes.

* **Resultado:** Las pruebas aisladas confirmaron la viabilidad de la rotación y el pivoteo a 90 grados.

#### Fase 2: pruebas de integración y detección de fallas

<p align="center">
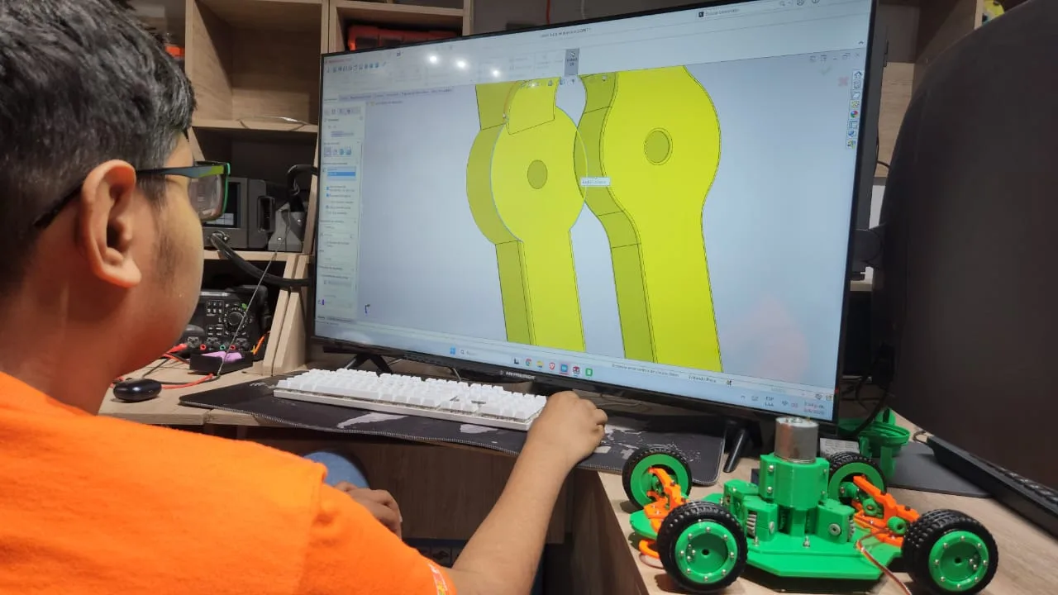
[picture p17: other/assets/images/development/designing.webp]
Diseño CAD del sistema de dirección
	
	<br>
	<i>Iteración de diseño en CAD entre prototipos impresos</i>
</p>

* **Sistema de Dirección:** Diseñamos una relación de palancas y piñones para la inversión de movimiento simultáneo. Se integraron **sensores Hall** para monitorear con precisión el ángulo de giro ante la necesidad de usar un servo de más de 360 grados.

* **Problemas detectados:**
  * Las barras de transmisión entre discos eran débiles: se doblaban, e incluso una llegó a quebrarse.
  * Las guayas generaban una tensión excesiva sobre el servomotor al ejecutar el giro.

* **Decisión:** Descartamos el sistema de guayas y palancas por ser complejo y pesado, buscando un mecanismo más ligero y directo.

#### Fase 3: rediseño a engranajes perpendiculares, coronas y correa dentada

<p align="center">
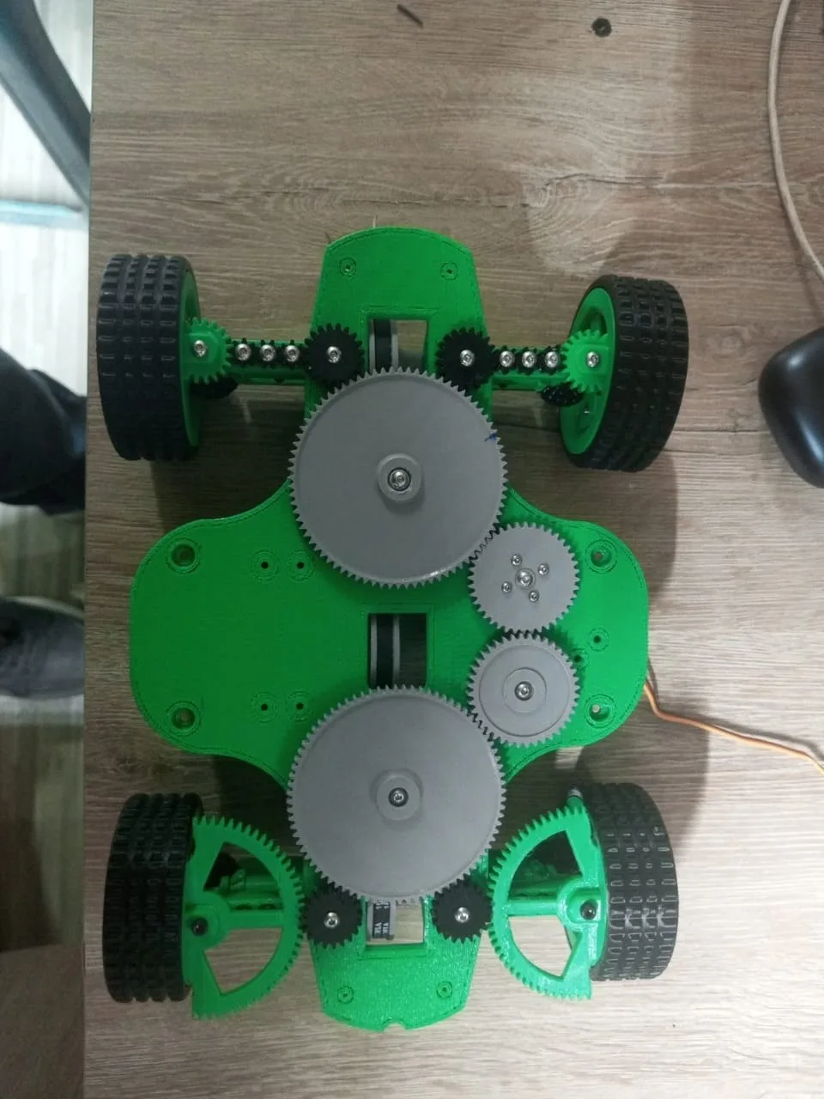
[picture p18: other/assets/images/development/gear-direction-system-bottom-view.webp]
Sistema de dirección por engranajes, vista inferior
	
	<br>
	<i>Sistema de dirección por engranajes, vista inferior: coronas integradas a los rines</i>
</p>

* **Nuevo Sistema de Tracción:** Eliminación de guayas. Se optó por **engranajes perpendiculares** ajustando el punto de pivote sobre el centro de la rueda, manteniendo los 90 grados de giro sin perder tracción.

* **Optimización de la dirección:**
  * La primera prueba con líneas de piñones pequeños generó juego entre dientes (*backlash*) y movimiento errático.
  * Se reemplazaron por una **corona más grande integrada al rin**, que da una conexión directa y precisa accionada por el servomotor único.

* **Sincronización 4x4:** Se unificaron los árboles de transmisión delantero y trasero mediante una **correa dentada con poleas**, logrando accionar las 4 ruedas simultáneamente con un solo motor.

#### Fase 4: optimización de peso, integración y chasis final

<p align="center">
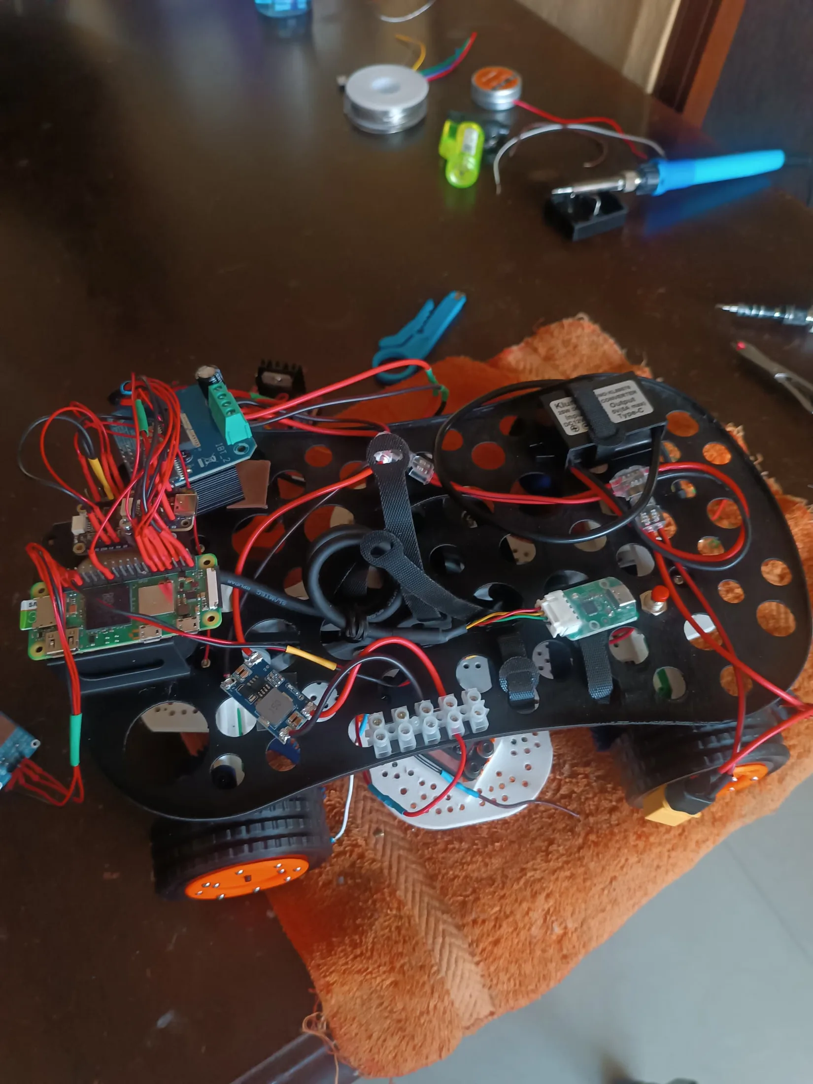
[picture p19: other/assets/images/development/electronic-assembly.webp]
Integración de electrónica sobre el monochasis
	
	<br>
	<i>Integración de la electrónica sobre el monochasis agujereado</i>
</p>

* **Distribución de Componentes:** Se diseñó una plataforma elevada para separar la electrónica de la mecánica. Esta posición permitió ubicar el RPLiDAR con unos 270° de arco útil: 230° continuos hacia el frente y los costados, más una ventana de unos 40° justo hacia atrás. Las cuñas que el propio chasis ocluye están medidas y declaradas en `src/config/navigation/sensors/lidar_sectors.toml`.

* **Control de Peso (1500 g):** al ensamblar el conjunto se detectó un exceso de 150 g, ya por debajo de los 200 g con los que arrancó el primer prototipo.

* **Acciones correctivas:**
  * Materiales de impresión más ligeros, como el ASA (acrilonitrilo estireno acrilato).
  * Reducción de la densidad de relleno en la impresión 3D.
  * Menor espesor de pared y vacíos estructurales en chasis, rines y bancadas, sin comprometer la rigidez.

* **Resultado Final:** Se logró ingresar dentro del rango de peso reglamentario y consolidar un chasis rígido impreso en 3D con soportes dedicados para la electrónica.

#### Fase 5: integración del REV HD Hex Motor

<p align="center">
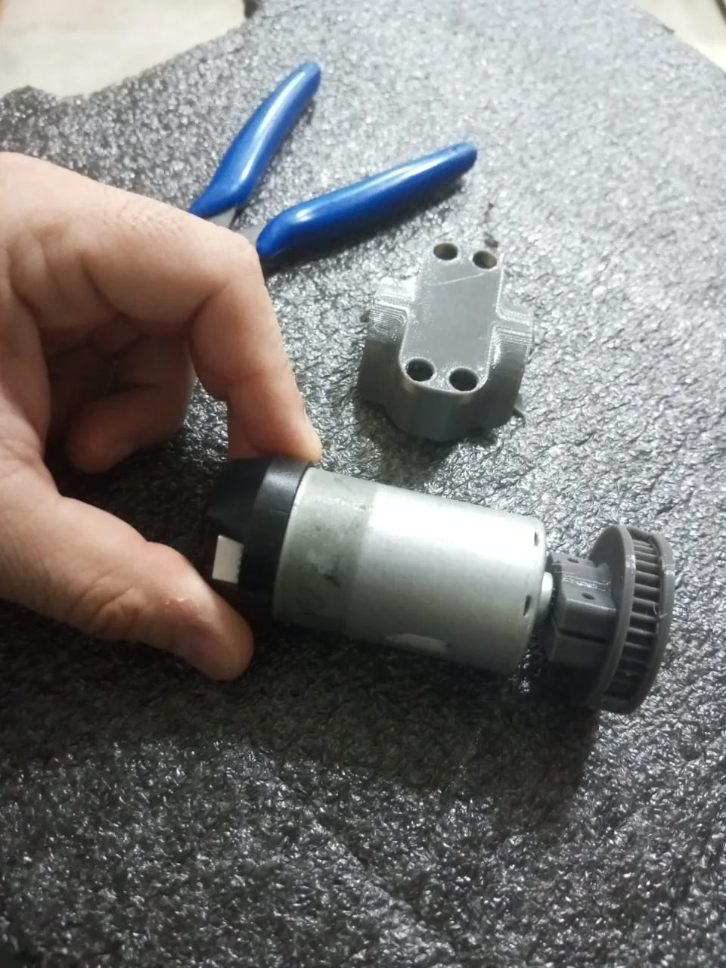
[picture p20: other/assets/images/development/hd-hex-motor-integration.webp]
Integración del REV HD Hex Motor al Sistema de Transmisión
	
	<br>
	<i>Integración del REV HD Hex Motor al Sistema de Transmisión</i>
</p>

* **Nuevo Motor**: tras el montaje final se detectó que el motor previo, un motor reductor genérico de 1500 rpm con encoder, no daba el torque necesario. Movía a vTitan, pero su techo de velocidad medido en pista era de **0.156 m/s** (unos 15 cm/s), con el que el robot no completaba los desafíos dentro del límite de tiempo. La solución más simple y efectiva fue sustituirlo por un **REV HD Hex Motor**, con 6000 rpm sin carga y 0.105 Nm de torque de bloqueo.

* **Resultado Final**: Tras adaptar el chasis inferior para el encaje del HD Hex Motor, la velocidad en pista subió de los 15 cm/s del motor anterior a 25-30 cm/s, y más tarde, al corregir el encoder, se descubrió que el techo real era de ~58 cm/s (ver [Velocidad: teórica contra real](#velocidad-teórica-contra-real)). De esta manera, vTitan tiene la velocidad necesaria para completar los desafíos sin exceder el tiempo límite establecido de 3 minutos.

### Sistema de transmisión

<p align="center">
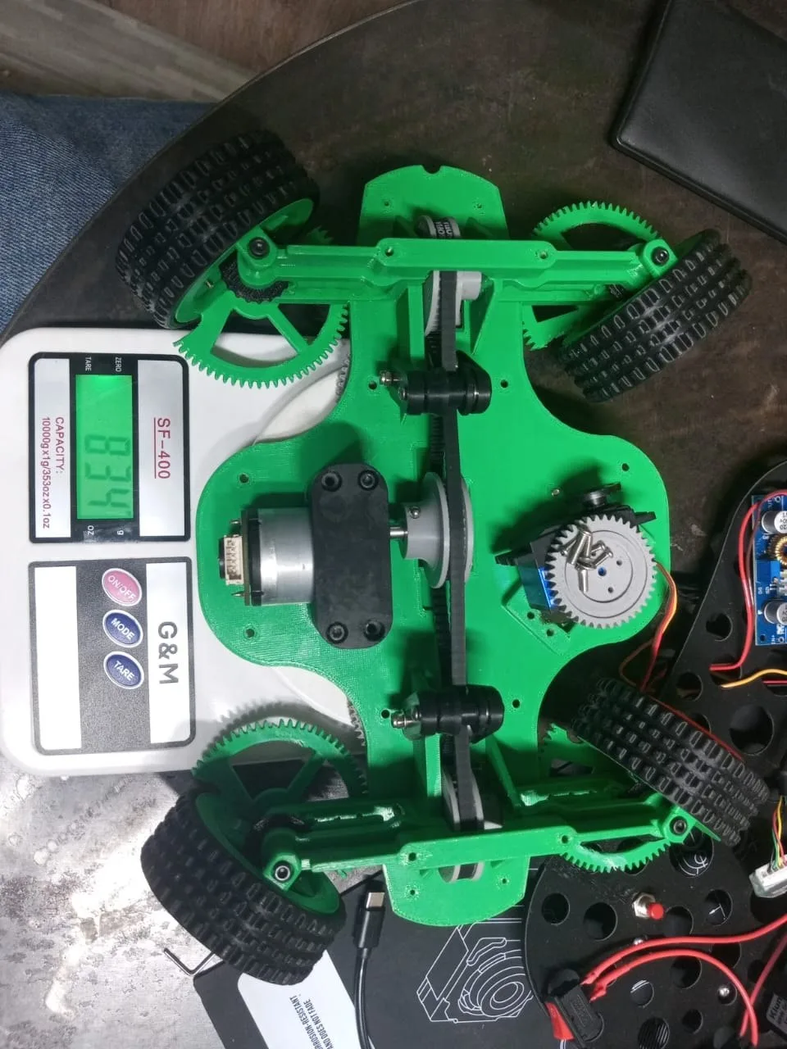
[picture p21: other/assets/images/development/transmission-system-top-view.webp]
	
	<br>
	<i>Sistema de Transmisión, visto desde arriba</i>
</p>

Para poder diseñar nuestro sistema de transmisión, tuvimos que tener en cuenta nuestra meta inicial de nuestro alcance de dirección, para poder transmitir el movimiento del motor hacia las ruedas aun cuando estén rotadas a un ángulo de 90 grados. 

Nuestro sistema de transmisión es 4x4 para maximizar la tracción en cada rueda, y lo gobierna un único motor. Del motor salen dos correas dentadas, una hacia el eje delantero y otra hacia el trasero, montados sobre pernos de transmisión de LEGO. Cada eje reparte el giro a un tren de engranajes cónicos por rueda, y el último de ellos engrana directamente con la corona interna de la rueda: en lugar de un caucho liso, la rueda recibe la tracción por sus propios dientes. Así las cuatro reciben la misma potencia. El rin no transmite nada; su función es sostener la corona y los engranajes cónicos. Los dientes de cada etapa están en la [tabla de relaciones](#relación-de-torque-y-velocidad).

### Sistema de dirección

<p align="center">
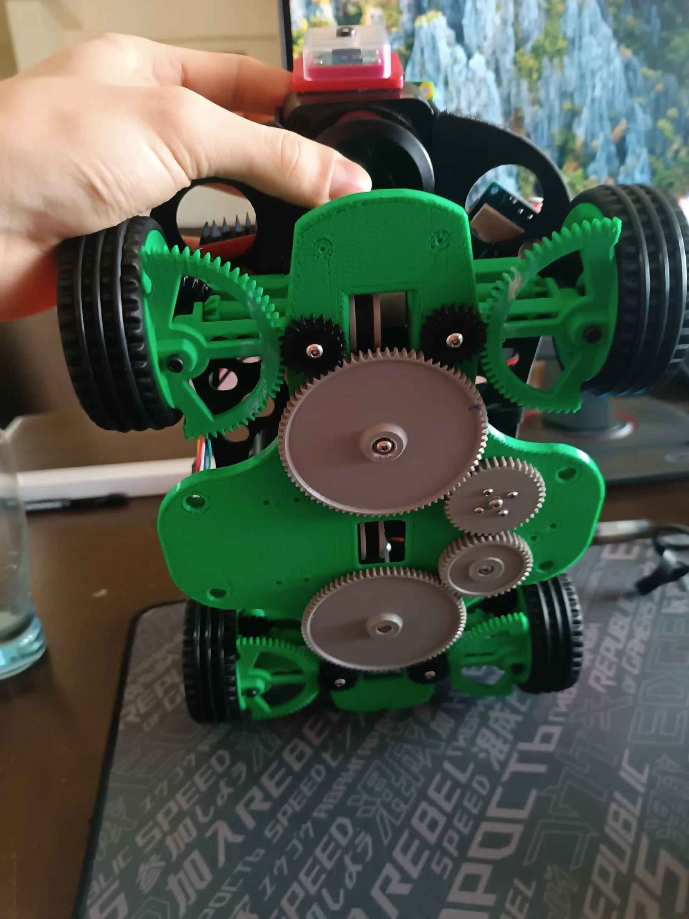
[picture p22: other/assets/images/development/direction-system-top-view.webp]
Sistema de Dirección
	
	<br>
	<i>Sistema de Dirección, visto desde arriba</i>
</p>

Como ya se ha mencionado previamente, nuestra meta principal con nuestro sistema de dirección es tener un giro de 90 grados para facilitar la ruta en pista, para lograr esto, tuvimos que replantear la solución mecánica de Klevor desde cero. 

<p align="center">
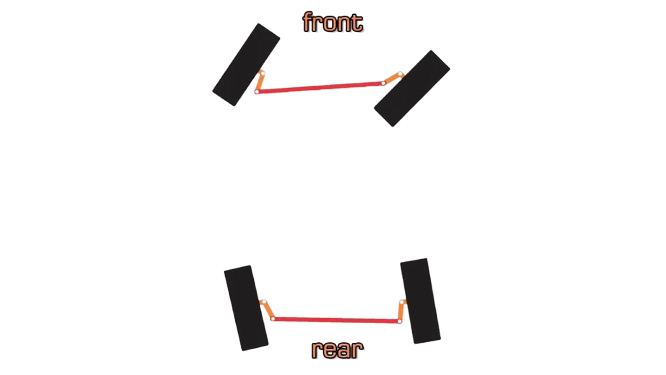
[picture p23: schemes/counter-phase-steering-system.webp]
Ejemplo de sistema de dirección en Contrafase
	
	<br>
	<i>Ejemplo de sistema de dirección en contrafase</i>
</p>

vTitan usa **dirección en contrafase**: las ruedas traseras giran en sentido opuesto a las delanteras, lo que reduce mucho el radio de giro y facilita maniobras como el estacionamiento y los giros cerrados, importantes en el Obstacle Challenge.

Todo el movimiento se transmite por engranajes, y los rines actúan a la vez como soporte y como actuador, porque llevan una base dentada. El precio es el par: al dirigir cuatro ruedas motrices, el servomotor tiene que vencer mucha más resistencia, y por eso sustituimos el servo anterior de 14 kg·cm por uno de 35 kg·cm.

En cuanto al mecanismo, en primer lugar al servo le implementamos un eje de 20 dientes, el cual se conecta luego a otro engranaje de 20 dientes para transmitir ese mismo movimiento pero en dirección opuesta, cada engranaje de 20 dientes luego transmite su movimiento a un engranaje de 40 dientes, el cual conecta con el engranaje individual que conecta finalmente con cada rueda, ya sean delanteras o traseras.

<p align="center">
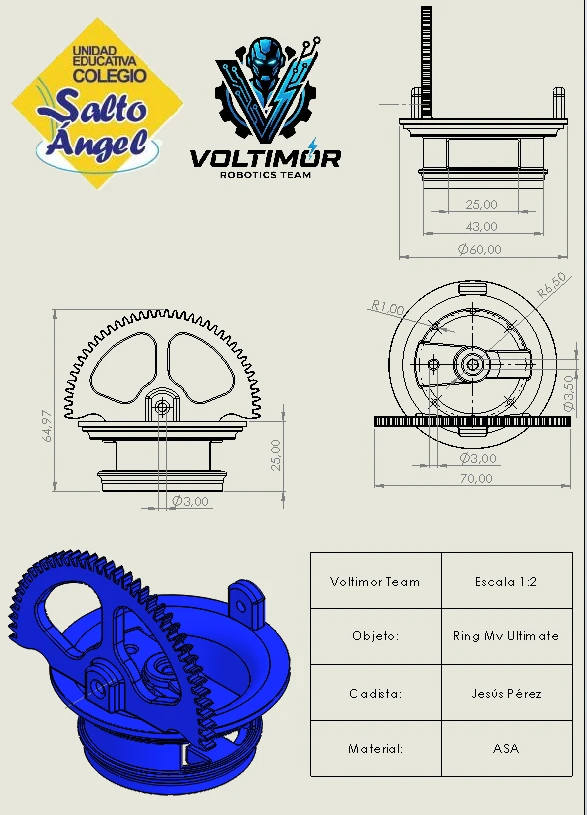
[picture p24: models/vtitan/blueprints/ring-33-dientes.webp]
Ring de 33 dientes
	
	<br>
	<i>Ring de 33 dientes</i>
</p>

También es importante recalcar la base dentada del rin de las ruedas, o mejor dicho, el piñón de dirección de la misma, debido a que el sistema de transmisión de vTitan en lugar de utilizar engranajes diferenciales estándar, utiliza una transmisión por engranajes a cada rueda, lo que permite que la rueda pueda seguir recibiendo la tracción aún cuando está a 90 grados.

**Radio de giro: predicho contra medido.** El simulador originalmente permitía radios de giro virtualmente ilimitados (hasta ~8 mm), muy por debajo de lo que la geometría real puede cumplir. La medición en banco del chasis real fijó el radio mínimo en **0.29 m**, y ese valor vive ahora como límite duro (`MIN_TURN_RADIUS_M` en `src/config/`) tanto en la simulación como en el controlador: el simulador ya no aprueba curvas que el chasis no puede trazar. La consecuencia práctica se midió después sobre bags reales: entre 57 y 59% de los pasos del pure pursuit exigían un radio menor al que el chasis puede entregar, lo que disparaba el corte de velocidad por rumbo; el corrector que descarta puntos de mira inalcanzables (`MIN_TARGET_RADIUS_M`, medido y aceptado en A/B sobre 128 casos) nació de esa medición. Es la diferencia entre diseñar contra un chasis que existe y uno que no.

<!-- HUECO (rubro WRO 2026, criterio 1 "Opciones del sistema de dirección").
Falta la comparación explícita Ackermann contra contrafase: por qué se descartó
Ackermann y qué se ganó con contrafase (giro de 90 grados para la salida del
estacionamiento). El diagrama schemes/ackermann-steering-system.webp existe y
schemes/README.md lo cataloga, pero esta sección todavía no lo usa. -->

### Estructura mecánica

El chasis de vTitan se reparte en dos piezas con responsabilidades distintas: el chasis inferior, que sostiene la transmisión y la dirección, y el monochasis, que cierra el conjunto y fija la electrónica.

#### Chasis inferior

<p align="center">
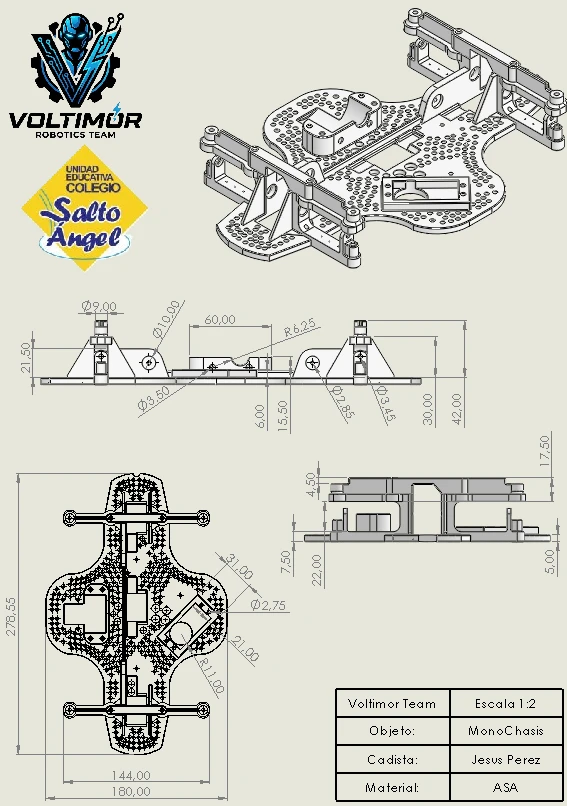
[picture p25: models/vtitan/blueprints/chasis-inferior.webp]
Chasis Inferior
	
	<br>
	<i>Chasis Inferior</i>
</p>

El chasis inferior es donde se implementan la transmisión y la dirección. Su rasgo más visible es la forma agujereada, que responde a las limitaciones de peso que arrastraba el primer prototipo. En el centro lleva dos encajes, uno para el motor y otro para el servomotor; en los extremos, los encajes de los ejes de transmisión, que usan pernos de LEGO para garantizar una unión rígida entre componentes y chasis.

#### Monochasis

**Dimensiones.** El conjunto ensamblado mide **300 × 194 × 100 mm** (largo × ancho × alto, medidos), con margen sobre los límites reglamentarios de 300 × 200 × 300 mm. El peso final dependió de la batería: con la de prácticas y sus conectores Deans el conjunto quedó en **~1510 g**, apenas por encima del límite de 1500 g, y el paso a la batería de competencia (shorty XT60, 46 g menos) junto con el cambio de conectores lo bajó a **~1460 g**, dentro del límite con ~40 g de margen. La geometría que consume el control (distancia entre ejes (wheelbase) de 0.19 m, vía de 0.1675 m entre ruedas, ruedas de 0.07 m de diámetro) reside en `src/config/robot.toml` como fuente única, y es la misma que usan la simulación, la TF estática y el generador de Gazebo.

### Montaje

<p align="center">
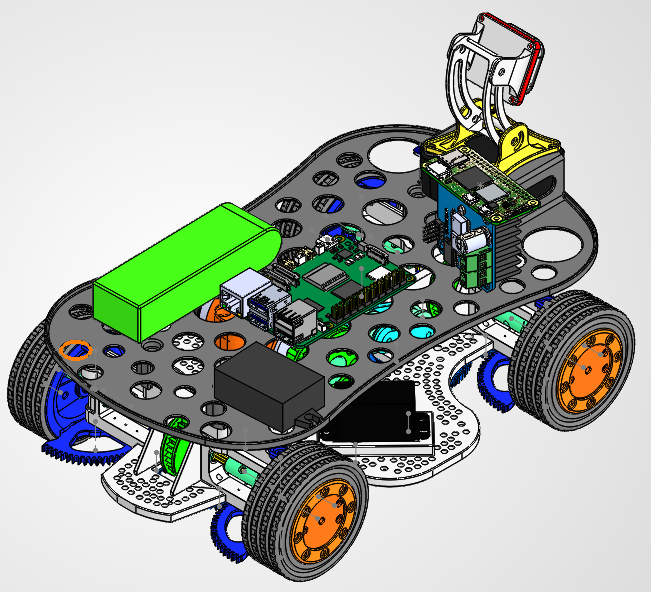
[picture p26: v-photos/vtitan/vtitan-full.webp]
Conjunto ensamblado de vTitan
	
	<br>
	<i>Conjunto ensamblado, renderizado desde el CAD</i>
</p>

Y el mismo conjunto despiezado, del mismo modelo de SolidWorks del que se exportan los archivos de [`models/vtitan/`](models/README.md):

<p align="center">
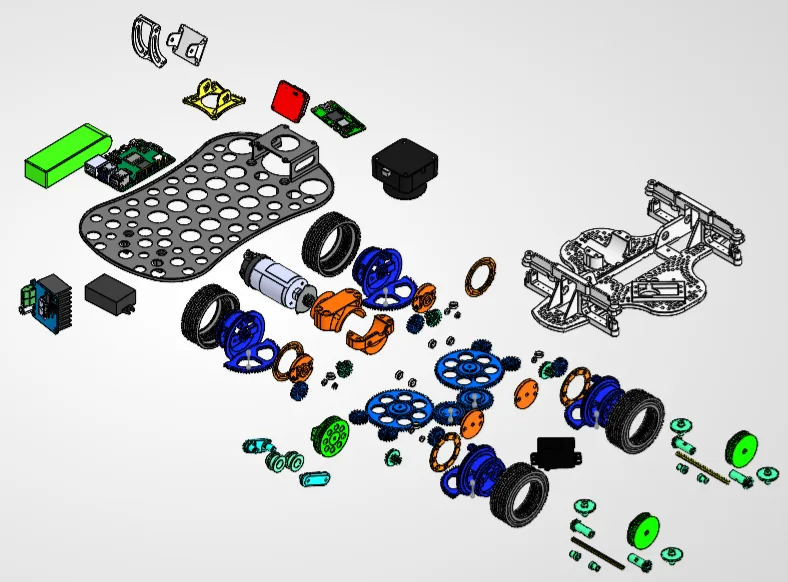
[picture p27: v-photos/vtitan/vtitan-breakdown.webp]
Vista despiezada de vTitan
	
	<br>
	<i>Vista despiezada de vTitan: chasis inferior, tren de transmisión, sistema de dirección y electrónica</i>
</p>

La misma vista despiezada con cada pieza numerada, y su tabla de elementos desplegable con el enlace a cada archivo disponible (el número de la tabla corresponde al globo de la vista):

<p align="center">
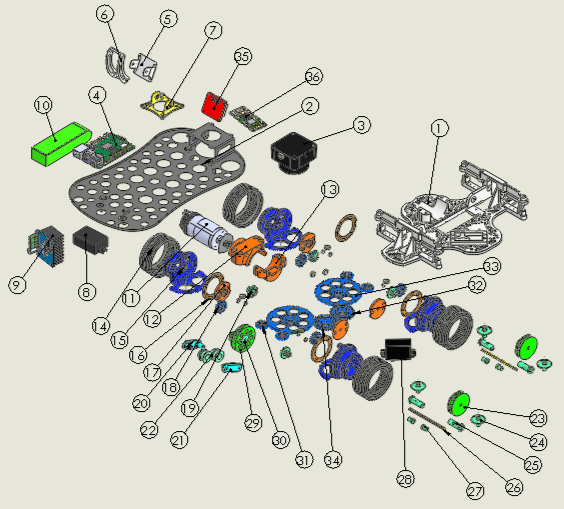
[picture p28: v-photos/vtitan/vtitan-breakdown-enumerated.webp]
Vista despiezada de vTitan con cada pieza numerada
	
	<br>
	<i>Vista despiezada numerada: cada globo enlaza con la tabla de elementos</i>
</p>

<details>
<summary><b>Tabla de elementos (39 piezas)</b></summary>

<table align="center">
<thead>
<tr>
<th align="center">N°</th>
<th align="left">Pieza</th>
<th align="center">Cantidad</th>
<th align="left">STL</th>
<th align="left">STEP</th>
</tr>
</thead>
<tbody>
<tr>
<td align="center">1</td>
<td align="left">Monochasis v3</td>
<td align="center">1</td>
<td align="left"><a href="models/vtitan/stl-files/monochasis-v3.stl">STL</a></td>
<td align="left">pendiente</td>
</tr>
<tr>
<td align="center">2</td>
<td align="left">Ring Mv v2</td>
<td align="center">4</td>
<td align="left"><a href="models/vtitan/stl-files/ring-mv-v2.stl">STL</a></td>
<td align="left">pendiente</td>
</tr>
<tr>
<td align="center">3</td>
<td align="left">Rueda vTitan</td>
<td align="center">4</td>
<td align="left"><a href="models/vtitan/stl-files/rueda-vtitan.stl">STL</a></td>
<td align="left">pendiente</td>
</tr>
<tr>
<td align="center">4</td>
<td align="left">Piñón de 40 dientes de dirección</td>
<td align="center">2</td>
<td align="left">pendiente</td>
<td align="left"><a href="models/vtitan/step-files/pinon-40-dientes-direccion.step">STEP</a></td>
</tr>
<tr>
<td align="center">5</td>
<td align="left">Piñón de 20 dientes de dirección (v2)</td>
<td align="center">4</td>
<td align="left"><a href="models/vtitan/stl-files/pinon-20-dientes-direccion-v2.stl">STL</a></td>
<td align="left">pendiente</td>
</tr>
<tr>
<td align="center">6</td>
<td align="left">Cubierta de ring</td>
<td align="center">4</td>
<td align="left"><a href="models/vtitan/stl-files/cubierta-de-ring.stl">STL</a></td>
<td align="left"><a href="models/vtitan/step-files/cubierta-de-ring.step">STEP</a></td>
</tr>
<tr>
<td align="center">7</td>
<td align="left">Aro de fijación axial de caucho</td>
<td align="center">4</td>
<td align="left"><a href="models/vtitan/stl-files/aro-de-fijacion-axial-de-caucho.stl">STL</a></td>
<td align="left"><a href="models/vtitan/step-files/aro-de-fijacion-axial-de-caucho.step">STEP</a></td>
</tr>
<tr>
<td align="center">8</td>
<td align="left">Buje guía de cruceta</td>
<td align="center">4</td>
<td align="left"><a href="models/vtitan/stl-files/buje-guia-de-cruceta.stl">STL</a></td>
<td align="left"><a href="models/vtitan/step-files/buje-guia-de-cruceta.step">STEP</a></td>
</tr>
<tr>
<td align="center">9</td>
<td align="left">Base del sistema de transmisión (corto)</td>
<td align="center">2</td>
<td align="left">pendiente</td>
<td align="left"><a href="models/vtitan/step-files/base-de-sistema-de-transmision-corto.step">STEP</a></td>
</tr>
<tr>
<td align="center">10</td>
<td align="left">Piñón de 33 dientes de correa</td>
<td align="center">2</td>
<td align="left"><a href="models/vtitan/stl-files/pinon-33-dientes-correa-dentada.stl">STL</a></td>
<td align="left"><a href="models/vtitan/step-files/pinon-33-dientes-correa-dentada.step">STEP</a></td>
</tr>
<tr>
<td align="center">11</td>
<td align="left">Piñón de 40 dientes de servo, con cajera</td>
<td align="center">1</td>
<td align="left"><a href="models/vtitan/stl-files/pinon-40-dientes-servo-cajera.stl">STL</a></td>
<td align="left"><a href="models/vtitan/step-files/pinon-40-dientes-servo-cajera.step">STEP</a></td>
</tr>
<tr>
<td align="center">12</td>
<td align="left">Piñón de 40 dientes de dirección, arrastre</td>
<td align="center">1</td>
<td align="left"><a href="models/vtitan/stl-files/pinon-40-dientes-direccion-arrastre.stl">STL</a></td>
<td align="left">pendiente</td>
</tr>
<tr>
<td align="center">13</td>
<td align="left">Servo de dirección (INJORA 14 kg)</td>
<td align="center">1</td>
<td align="left">pendiente</td>
<td align="left">pendiente</td>
</tr>
<tr>
<td align="center">14</td>
<td align="left">Piñón 90 de cruceta, 10 dientes</td>
<td align="center">4</td>
<td align="left"><a href="models/vtitan/stl-files/pinon-90-cruceta-10-dientes.stl">STL</a></td>
<td align="left"><a href="models/vtitan/step-files/pinon-90-cruceta-10-dientes.step">STEP</a></td>
</tr>
<tr>
<td align="center">15</td>
<td align="left">Piñón cónico de 20 dientes</td>
<td align="center">4</td>
<td align="left"><a href="models/vtitan/stl-files/pinon-conico-20-dientes.stl">STL</a></td>
<td align="left"><a href="models/vtitan/step-files/pinon-conico-20-dientes.step">STEP</a></td>
</tr>
<tr>
<td align="center">16</td>
<td align="left">Rolinera 3 x 7 x 2</td>
<td align="center">8</td>
<td align="left">pendiente</td>
<td align="left"><a href="models/vtitan/step-files/rolinera-3-7-2.step">STEP</a></td>
</tr>
<tr>
<td align="center">17</td>
<td align="left">Rolinera 6.35 x 9.525 x 3.175</td>
<td align="center">5</td>
<td align="left">pendiente</td>
<td align="left"><a href="models/vtitan/step-files/rolinera-6.35-9.525-3.175.step">STEP</a></td>
</tr>
<tr>
<td align="center">18</td>
<td align="left">Piñón de 20 dientes de rueda dentada (v2)</td>
<td align="center">4</td>
<td align="left"><a href="models/vtitan/stl-files/pinon-20-dientes-rueda-dentada-v2.stl">STL</a></td>
<td align="left">pendiente</td>
</tr>
<tr>
<td align="center">19</td>
<td align="left">Piñón cónico 15 x 8 dientes</td>
<td align="center">4</td>
<td align="left"><a href="models/vtitan/stl-files/pinon-conico-15x8-dientes.stl">STL</a></td>
<td align="left"><a href="models/vtitan/step-files/pinon-conico-15x8-dientes.step">STEP</a></td>
</tr>
<tr>
<td align="center">20</td>
<td align="left">Cámara Camera Module 3 v8</td>
<td align="center">1</td>
<td align="left">pendiente</td>
<td align="left"><a href="models/vtitan/step-files/camera-module-3-v8.step">STEP</a></td>
</tr>
<tr>
<td align="center">21</td>
<td align="left">Batería Ovonic Air Li-Po</td>
<td align="center">1</td>
<td align="left">pendiente</td>
<td align="left"><a href="models/vtitan/step-files/ovonic-air-lipo-battery.step">STEP</a></td>
</tr>
<tr>
<td align="center">22</td>
<td align="left">Raspberry Pi 5</td>
<td align="center">1</td>
<td align="left">pendiente</td>
<td align="left"><a href="models/vtitan/step-files/raspberry-pi-5.step">STEP</a></td>
</tr>
<tr>
<td align="center">23</td>
<td align="left">RPLiDAR C1</td>
<td align="center">1</td>
<td align="left">pendiente</td>
<td align="left"><a href="models/vtitan/step-files/rplidar-c1.step">STEP</a></td>
</tr>
<tr>
<td align="center">24</td>
<td align="left">Suplemento de bancada de motor pequeño</td>
<td align="center">1</td>
<td align="left"><a href="models/vtitan/stl-files/suplemento-de-bancada-motor-pequeno.stl">STL</a></td>
<td align="left">pendiente</td>
</tr>
<tr>
<td align="center">25</td>
<td align="left">Motor REV-41-1600</td>
<td align="center">1</td>
<td align="left">pendiente</td>
<td align="left">pendiente</td>
</tr>
<tr>
<td align="center">26</td>
<td align="left">Engranaje unificado de motor REV, 36 dientes</td>
<td align="center">1</td>
<td align="left"><a href="models/vtitan/stl-files/engranaje-unificado-motor-rev-36-dientes.stl">STL</a></td>
<td align="left">pendiente</td>
</tr>
<tr>
<td align="center">27</td>
<td align="left">Tapa de bancada de motor REV</td>
<td align="center">1</td>
<td align="left"><a href="models/vtitan/stl-files/tapa-de-bancada-motor-rev.stl">STL</a></td>
<td align="left">pendiente</td>
</tr>
<tr>
<td align="center">28</td>
<td align="left">Brazo de tensor v2 largo</td>
<td align="center">1</td>
<td align="left"><a href="models/vtitan/stl-files/brazo-de-tensor-v2-largo.stl">STL</a></td>
<td align="left">pendiente</td>
</tr>
<tr>
<td align="center">29</td>
<td align="left">Rodillo tensor v2</td>
<td align="center">2</td>
<td align="left"><a href="models/vtitan/stl-files/rodillo-tensor-v2.stl">STL</a></td>
<td align="left">pendiente</td>
</tr>
<tr>
<td align="center">30</td>
<td align="left">Brazo de tensor v3</td>
<td align="center">1</td>
<td align="left"><a href="models/vtitan/stl-files/brazo-de-tensor-v3.stl">STL</a></td>
<td align="left">pendiente</td>
</tr>
<tr>
<td align="center">31</td>
<td align="left">Soporte superior</td>
<td align="center">1</td>
<td align="left"><a href="models/vtitan/stl-files/soporte-superior.stl">STL</a></td>
<td align="left"><a href="models/vtitan/step-files/soporte-superior.step">STEP</a></td>
</tr>
<tr>
<td align="center">32</td>
<td align="left">Carcasa de la cámara</td>
<td align="center">1</td>
<td align="left">pendiente</td>
<td align="left">pendiente</td>
</tr>
<tr>
<td align="center">33</td>
<td align="left">Soporte inferior de cámara</td>
<td align="center">1</td>
<td align="left"><a href="models/vtitan/stl-files/soporte-camara-inferior.stl">STL</a></td>
<td align="left">pendiente</td>
</tr>
<tr>
<td align="center">34</td>
<td align="left">Soporte de cámara superior</td>
<td align="center">1</td>
<td align="left"><a href="models/vtitan/stl-files/soporte-camara-superior.stl">STL</a></td>
<td align="left">pendiente</td>
</tr>
<tr>
<td align="center">35</td>
<td align="left">Soporte de cámara, brazo intermedio</td>
<td align="center">1</td>
<td align="left"><a href="models/vtitan/stl-files/soporte-camara-brazo-intermedio.stl">STL</a></td>
<td align="left">pendiente</td>
</tr>
<tr>
<td align="center">36</td>
<td align="left">Raspberry Pi Zero 2 W</td>
<td align="center">1</td>
<td align="left">pendiente</td>
<td align="left">pendiente</td>
</tr>
<tr>
<td align="center">37</td>
<td align="left">Klunox</td>
<td align="center">1</td>
<td align="left">pendiente</td>
<td align="left">pendiente</td>
</tr>
<tr>
<td align="center">38</td>
<td align="left">Sensor de color APDS9960</td>
<td align="center">1</td>
<td align="left">pendiente</td>
<td align="left">pendiente</td>
</tr>
<tr>
<td align="center">39</td>
<td align="left">Puente H IBT-2 (BTS7960)</td>
<td align="center">1</td>
<td align="left">pendiente</td>
<td align="left">pendiente</td>
</tr>
</tbody>
</table>

> [!NOTE]
> **pendiente** significa que el archivo todavía no está publicado en `models/` y queda por agregar.

</details>

El conjunto se ordena en tres capas: el **chasis inferior** perforado sostiene el motor y el servomotor en sus encajes centrales; sobre él se monta el **tren de transmisión** (correas dentadas hacia los dos ejes, y de cada eje a los engranajes cónicos de cada rueda); y el **monochasis** cierra el conjunto y fija la electrónica. Los ejes usan pernos de transmisión de LEGO, elegidos por su ajuste rígido y porque evitan mecanizar un eje a medida.

#### Las piezas, y cómo mirarlas

Publicamos cada pieza en **dos formatos**, porque sirven para cosas distintas:

<table align="center">
<thead>
<tr>
<th align="left">Formato</th>
<th align="left">Archivos</th>
<th align="left">Para qué</th>
</tr>
</thead>
<tbody>
<tr>
<td align="left"><a href="models/vtitan/step-files/"><code>step-files/</code></a></td>
<td align="left">29 <code>.step</code></td>
<td align="left"><strong>Fabricar y editar.</strong> Conserva la geometría exacta, así que se puede reabrir y modificar en cualquier CAD</td>
</tr>
<tr>
<td align="left"><a href="models/vtitan/stl-files/"><code>stl-files/</code></a></td>
<td align="left">47 <code>.stl</code></td>
<td align="left"><strong>Imprimir y mirar.</strong> GitHub renderiza los <code>.stl</code> en un <strong>visor 3D interactivo</strong>: pincha cualquiera y podrás girarlo, desplazarlo y acercarlo en el navegador, sin instalar nada</td>
</tr>
</tbody>
</table>

Una pieza que existe en los dos formatos **lleva el mismo nombre** en ambos, que es lo que permite emparejarlas de un vistazo. 17 de las 29 piezas en `.step` tienen su `.stl`; las 12 restantes son componentes comerciales (Raspberry Pi 5, cámara, RPLiDAR, batería, rodamientos) que modelamos para el ensamblaje virtual y nunca se imprimen.

Algunas piezas para empezar, cada enlace abre el visor 3D de GitHub:

<table align="center">
<thead>
<tr>
<th align="center">Vista</th>
<th align="left">Pieza</th>
<th align="left">Subsistema</th>
</tr>
</thead>
<tbody>
<tr>
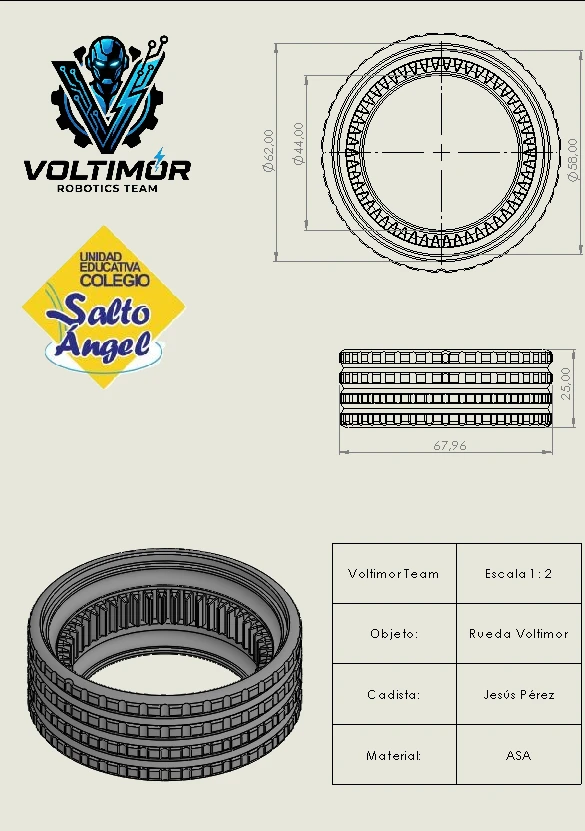
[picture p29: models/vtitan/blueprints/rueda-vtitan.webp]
<td align="center"></td>
<td align="left"><a href="models/vtitan/stl-files/rueda-vtitan.stl"><code>rueda-vtitan.stl</code></a></td>
<td align="left">La rueda con corona dentada interna</td>
</tr>
<tr>
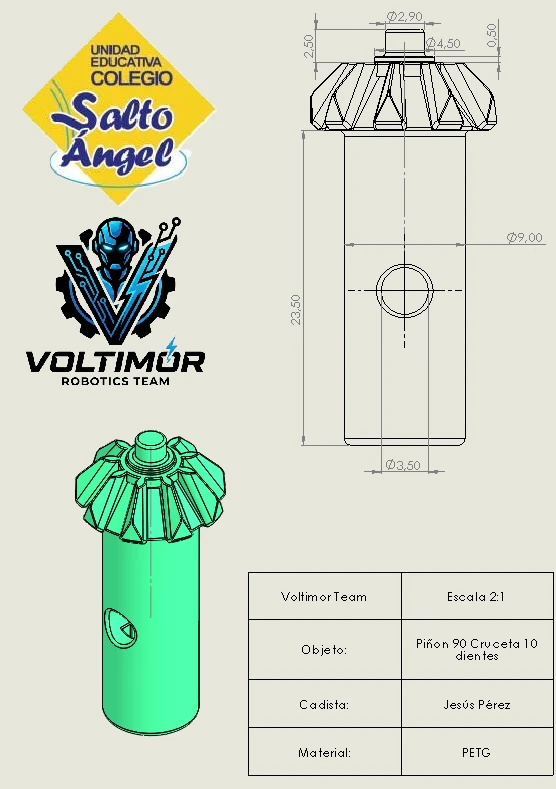
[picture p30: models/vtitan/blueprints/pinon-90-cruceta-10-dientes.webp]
<td align="center"></td>
<td align="left"><a href="models/vtitan/stl-files/pinon-90-cruceta-10-dientes.stl"><code>pinon-90-cruceta-10-dientes.stl</code></a></td>
<td align="left">El engranaje cónico que lleva la tracción a la rueda a 90°</td>
</tr>
<tr>
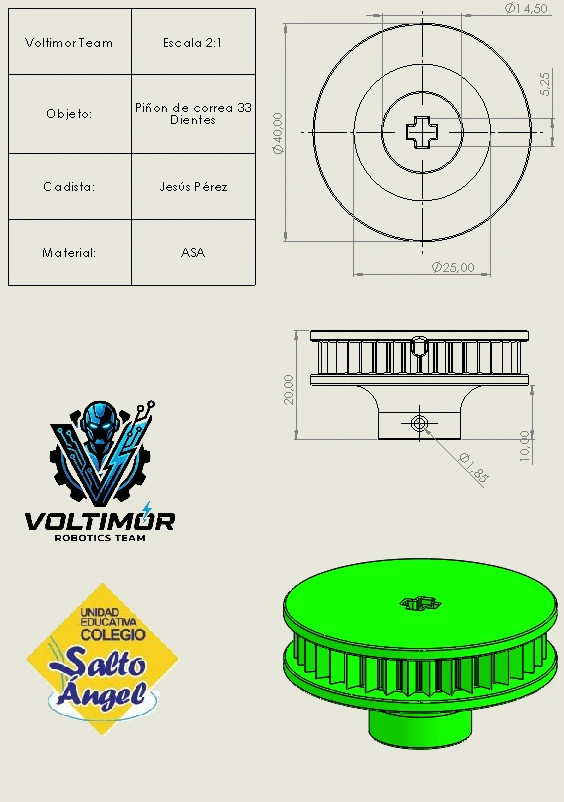
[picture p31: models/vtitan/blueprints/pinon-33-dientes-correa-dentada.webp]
<td align="center"></td>
<td align="left"><a href="models/vtitan/stl-files/pinon-33-dientes-correa-dentada.stl"><code>pinon-33-dientes-correa-dentada.stl</code></a></td>
<td align="left">El piñón de correa de 33 dientes, la entrada de la tracción</td>
</tr>
<tr>
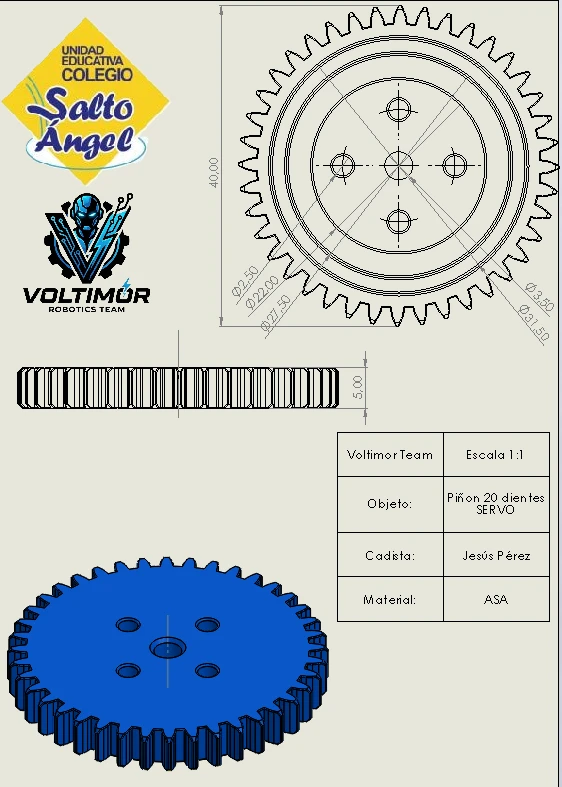
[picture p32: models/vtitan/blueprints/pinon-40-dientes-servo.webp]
<td align="center"></td>
<td align="left"><a href="models/vtitan/stl-files/pinon-40-dientes-servo-cajera.stl"><code>pinon-40-dientes-servo-cajera.stl</code></a></td>
<td align="left">El piñón del eje del servo, la entrada de la dirección</td>
</tr>
<tr>
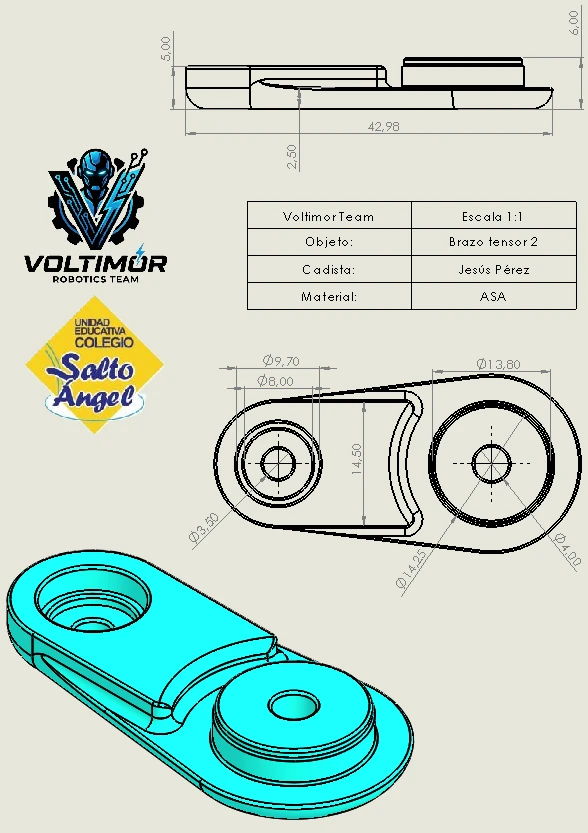
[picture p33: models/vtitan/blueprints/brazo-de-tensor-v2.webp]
<td align="center"></td>
<td align="left"><a href="models/vtitan/stl-files/brazo-de-tensor-v2.stl"><code>brazo-de-tensor-v2.stl</code></a></td>
<td align="left">El tensor que mantiene la correa dentada</td>
</tr>
<tr>
<td align="center">(sin plano)</td>
<td align="left"><a href="models/vtitan/stl-files/monochasis-v3.stl"><code>monochasis-v3.stl</code></a></td>
<td align="left">La estructura que cierra el conjunto (última iteración)</td>
</tr>
</tbody>
</table>

La miniatura es el plano acotado de la pieza, y **tanto la miniatura como el nombre abren el visor 3D de GitHub**. Un `.stl` no se puede incrustar en Markdown: GitHub solo lo renderiza en la página del propio archivo, así que el enlace es la única forma de llegar al visor.

El inventario completo, subsistema por subsistema, está en [`models/README.md`](models/README.md).

<!-- HUECO (rubro WRO 2026, criterio 1 "Montaje", lo que sigue faltando).
La vista despiezada y el inventario de piezas ya están arriba, pero falta lo que
hace el montaje REPRODUCIBLE: orden de armado paso a paso, tornillería (métrica y
longitud por posición), par de apriete, y los parámetros de impresión por pieza
(material, altura de capa, relleno, soportes, orientación de cama). -->

### Relación de torque y velocidad

Ahora bien, en el caso de vTitan, este utiliza un [REV HD Hex Motor](#rev-hd-hex-motor), el cual tiene un torque de bloqueo (es decir, su torque máximo) de 0.105 Nm, y una velocidad sin carga de 6000 RPM, ahora bien, ¿cómo podemos saber si este torque es necesario para mover a vTitan?

La fórmula general para calcular el torque necesario es:

$$T = \frac{m \cdot \left( a + g \cdot \left( \mu \cos\theta + \sin\theta \right) \right) \cdot r}{N}$$

Donde:

- $m$ es la masa del vehículo (en kg; en vTitan son **~1.51 kg con la batería de prácticas y ~1.46 kg con la de competencia**, medidos en el robot ensamblado). La simulación usa 1.5 kg fijos (`src/config/robot.toml`: chasis de 1.3 kg más 4 ruedas de 0.05 kg), un punto medio conservador entre ambas configuraciones: calcular con la masa mayor nunca subestima el torque necesario
- $r$ es el radio de la rueda (en metros; en vTitan mide $0.035\ \text{m}$)
- $a$ es la aceleración deseada. La **medimos sobre bags MCAP de pista real**: la derivada de la velocidad del encoder (`/motor/drive_speed`) sobre 5 carreras recientes da una aceleración sostenida de **~1.0 m/s²** (muy consistente: 0.93-1.09 en los 5 bags) y una rampa de arranque desde reposo de **~0.4 m/s²**. Usamos $a = 1.0\ \text{m/s}^2$, el caso conservador
- $g$ es la gravedad, $9.81\ \text{m/s}^2$
- $\mu$ es el coeficiente de fricción (estimamos $0.3$ para ruedas de ASA sobre lona de PVC flexible)
- $\theta$ es el ángulo de inclinación ($\theta = 0°$ en esta competición)
- $N$ es el número de motores en tracción (en vTitan solo hay uno)

Al efectuar toda la operación obtenemos como resultado que se necesita un torque mínimo de $0.207\ \text{Nm}$ para que vTitan sostenga la aceleración medida ($1.0\ \text{m/s}^2$). Para referencia: con solo fricción ($a = 0$) el requerimiento baja a $0.155\ \text{Nm}$, y con la rampa de arranque ($0.4\ \text{m/s}^2$) a $0.176\ \text{Nm}$.

Así que, como el torque de bloqueo del motor ($0.105\ \text{Nm}$) es menor al torque mínimo ($0.207\ \text{Nm}$), es evidente que el motor por sí solo no podría mover a vTitan sin utilizar algún método para aumentar el torque del motor de forma mecánica, la manera en la que resolvimos este problema es mediante las relaciones de engranajes, las cuales operan mediante la siguiente formula:

<p align="center">
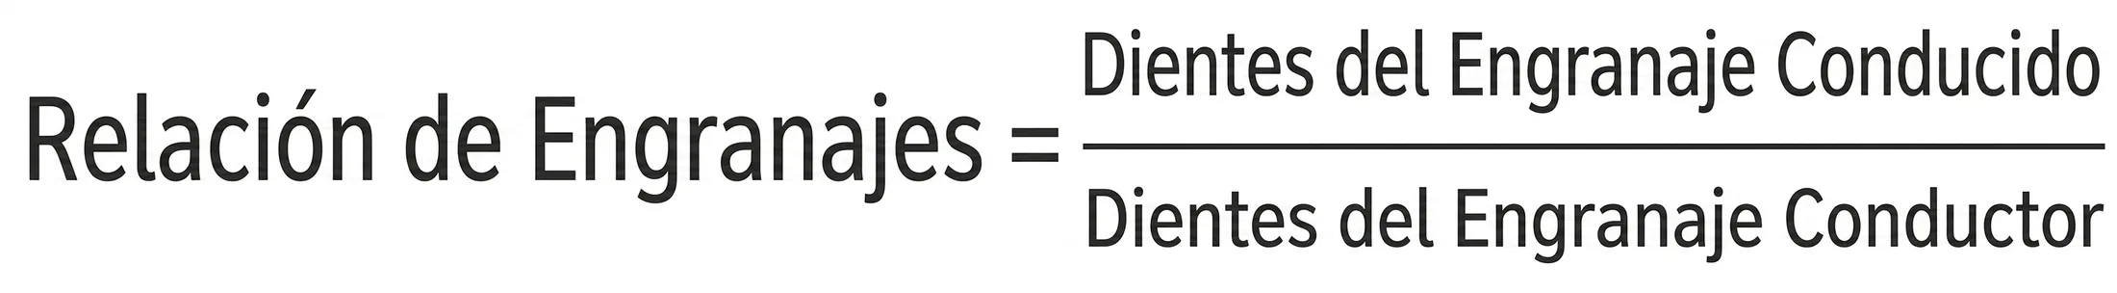
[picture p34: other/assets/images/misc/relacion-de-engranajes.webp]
Relación de Engranajes
	
	<br>
	<i>Relación de Engranajes</i>
</p>

El torque final, o de salida será igual a la multiplicación del torque inicial por la misma relación de engranajes total, ahora, simplemente hay que calcular la relación de transmisión total, para la cual simplemente calculamos cada relación individual y se efectúa el producto de ese conjunto:

| Etapa | Transmisión | Relación |
|---|---|---|
| 1 | Eje del motor (50 dientes) → correa hacia cada eje (33 dientes) | $i_1 = 33/50 = 0.66$ |
| 2 | Pernos de transmisión de LEGO con engranaje cónico de 10 dientes → engranaje de 20 dientes | $i_2 = 20/10 = 2$ |
| 3 | Engranaje de 20 dientes → engranaje de 15 dientes | $i_3 = 15/20 = 0.75$ |
| 4 | Engranaje de 15 dientes → engranaje de 20 dientes | $i_4 = 20/15 \approx 1.33$ |
| 5 | Engranaje de 20 dientes → rueda dentada de 50 dientes | $i_5 = 50/20 = 2.5$ |

La relación de transmisión total es el producto de las cinco etapas:

$$R_{total} = i_1 \cdot i_2 \cdot i_3 \cdot i_4 \cdot i_5 = 0.66 \cdot 2 \cdot 0.75 \cdot 1.33 \cdot 2.5 = 3.29$$

Y el torque de bloqueo final:

$$T_{final} = T_{stall} \cdot R_{total} = 0.105\ \text{Nm} \cdot 3.29 = 0.345\ \text{Nm}$$

Una recomendación habitual para los motores DC es utilizar el 50% de su torque de bloqueo para aceleraciones y tramos cortos, ahora bien, $0.345 \cdot 0.5 = 0.173\ \text{Nm}$, que queda por debajo del requerimiento con la aceleración sostenida medida ($0.207\ \text{Nm}$). Esto no invalida el diseño, y los bags lo confirman: la recomendación del 50% es para **funcionamiento continuo prolongado** (donde el calentamiento del devanado manda), mientras que la demanda real de una ronda es de tramos cortos de aceleración entre cruces; para eso están los picos de torque que los motores DC toleran por breves segundos. Contra el torque de bloqueo completo ($0.345\ \text{Nm}$), el margen es holgado incluso con $a = 1.0\ \text{m/s}^2$. La prueba final es empírica: los mismos bags de donde salió la aceleración muestran al robot sosteniendo esos $1.0\ \text{m/s}^2$ en pista, con este mismo motor y esta misma relación. Además, a medida que el vehículo gana velocidad, el coeficiente de fricción disminuye considerablemente (alrededor de un 15%), por lo que el torque necesario baja y es más fácil que el vehículo gane aceleración.

#### Velocidad: teórica contra real

El lado de la velocidad se verifica igual que el del torque: predicción, medición y explicación de la brecha.

**Techo cinemático.** Con el motor a su velocidad sin carga de 6000 RPM y la relación total $R_{total} = 3.29$, las ruedas girarían a $6000 / 3.29 \approx 1824$ RPM; con ruedas de 0.07 m de diámetro:

$$v_{teórico} = \frac{1824}{60} \cdot \pi \cdot 0.07 \approx 6.7\ \text{m/s}$$

**Medición en banco, con carga.** El motor nunca ve 6000 RPM en pista. La ley medida en banco (cargado, cinta métrica contra lo que el encoder cree recorrer) es afín: $\text{rpm} = 434.6 \cdot \text{duty} - 86.7$ ($R^2 = 0.9999$), con zona muerta en duty 0.200 y un techo físico de 348 RPM de rueda a duty 1.0, es decir **1.28 m/s**. El robot opera además con el ciclo de trabajo limitado al 50% por térmica, y los perfiles de velocidad de carrera (CREEP/SLOW/MEDIUM/FAST) viven dentro de ese presupuesto: la prealimentación afín `duty = 0.20 + 0.8 · rpm/max_rpm` (medida, con la misma zona muerta) les asigna ciclos de trabajo de 0.295 a 0.419.

**Resultado en pista.** El techo real medido es **~0.58 m/s**. No es un límite físico del motor: es el resultado combinado del tope del 50% de duty, de la zona muerta con carga (20% del duty se gasta en vencer la fricción) y de los perfiles de velocidad que el gobernador impone. La brecha contra el techo cinemático (~11x) queda así explicada: es la diferencia entre el motor sin carga de la hoja de datos y el motor cargado del banco con su ciclo de trabajo limitado. La cadena completa de esta medición (y del error de cuantización que antes la limitaba a 0.45 m/s) está en `src/config/hardware/motors/profiles/rev-hd-hex-motor-6000rpm/encoder.toml` y en la sección del [lazo de velocidad](#algoritmo-pid).

## Arquitectura de energía y sensores

Esta sección cubre la electrónica de vTitan: qué sensores lleva, por qué elegimos cada uno, cómo se integran y cuánta energía consumen.

### Lista de componentes
A continuación, está la descripción de todos los componentes principales de vTitan.

#### Raspberry Pi 5 (16 GB de RAM)

<p align="center">
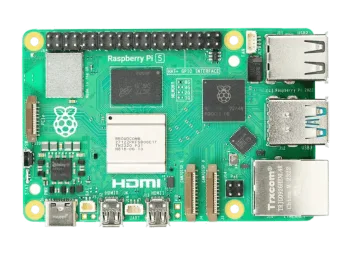
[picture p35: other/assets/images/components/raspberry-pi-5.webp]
Raspberry Pi 5
	
	<br>
	<i>Raspberry Pi 5</i>
</p>

Equipada con un procesador ARM Cortex-A76 de 64 bits a 2.4 GHz. La Raspberry Pi 5 es nuestro controlador principal. La elegimos por tres motivos:

- **Compatibilidad**: Existen muchos componentes de vTitan (como la Camera Module 3 Wide) que a su vez pertenecen al ecosistema Raspberry, lo que hace que implementarlos a la Raspberry Pi 5 no requiera tanto esfuerzo.

- **Potencia**: La Raspberry Pi 5 es uno de los computadores de placa única más potentes que se pueden comprar hoy, y eso pone el procesamiento de imágenes en tiempo real dentro de su alcance.

- **Portabilidad**: La Raspberry Pi 5 destaca entre los controladores, porque pesa apenas 46 g, lo que hace que montarla en vTitan no comprometa el presupuesto de peso.

<table align="center">
<thead>
<tr>
<th align="center"><strong>Medida</strong></th>
<th align="center"><strong>Valor</strong></th>
</tr>
</thead>
<tbody>
<tr>
<td align="center">Largo</td>
<td align="center">85 mm</td>
</tr>
<tr>
<td align="center">Alto</td>
<td align="center">58.9 mm</td>
</tr>
<tr>
<td align="center">Ancho</td>
<td align="center">56 mm</td>
</tr>
<tr>
<td align="center">Peso</td>
<td align="center">46 g</td>
</tr>
</tbody>
</table>

#### Raspberry Pi Camera Module 3 Wide

<p align="center">
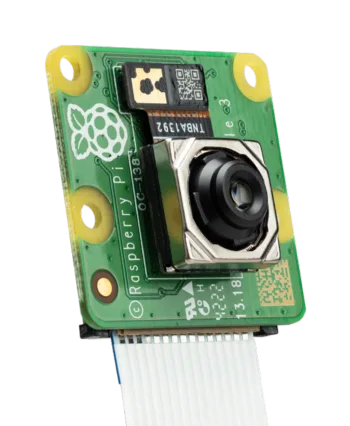
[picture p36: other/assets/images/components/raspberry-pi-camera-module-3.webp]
Raspberry Pi Camera Module 3
	
	<br>
	<i>Raspberry Pi Camera Module 3</i>
</p>

Como el resto de los componentes Raspberry, destaca por lo ligera y compacta: 25 × 24 × 12.4 mm y 4 gramos, sin sacrificar resolución, porque alcanza 1536 × 864 a 120 fps. Elegimos la versión Wide por su campo de visión horizontal de 102 grados, que es lo que nos permite ver todos los obstáculos de la pista y ganar autonomía.

<table align="center">
<thead>
<tr>
<th align="center"><strong>Medida</strong></th>
<th align="center"><strong>Valor</strong></th>
</tr>
</thead>
<tbody>
<tr>
<td align="center">Largo</td>
<td align="center">24 mm</td>
</tr>
<tr>
<td align="center">Alto</td>
<td align="center">25 mm</td>
</tr>
<tr>
<td align="center">Ancho</td>
<td align="center">12.4 mm</td>
</tr>
<tr>
<td align="center">Peso</td>
<td align="center">4 g</td>
</tr>
</tbody>
</table>

**Montaje.** La cámara va montada directamente sobre el LIDAR (mismo desplazamiento frontal, x = 0.1222 m), a unos **20 cm del suelo** e inclinada **~10° hacia abajo**. La posición alta cumple dos funciones: despeja la línea de visión sobre el propio chasis y sobre los obstáculos bajos de la pista, y junto con la inclinación leve hacia abajo equilibra el cuadro entre la pista cercana (donde aparecen las señales que hay que leer a tiempo para decidir el lado de paso) y el horizonte del pasillo. El ángulo es lo bastante pequeño para que las señales a distancia de decisión (~1.4 m de radio de activación) queden bien dentro del encuadre, sin sacrificar la visión lejana que da la versión Wide. Las constantes de montaje viven en `src/config/robot.toml` (`[camera]`), y son las mismas que consumen la simulación y la TF estática.

**Calibración.** No hacemos calibración intrínseca de fábrica: el detector no necesita proyectar píxeles con precisión métrica, porque la decisión de la distancia al obstáculo la toma el LIDAR (la visión **no** es la red de seguridad de colisiones). Para las señales, la cámara aporta rumbo (preciso: la posición horizontal en el cuadro no depende de la profundidad) y color, mientras que la distancia por altura del cuadro delimitador (bounding box) es un modelo pinhole (proyección estenopeica) cuyo error crece con el rango (~3.6 cm a 1.5 m, ~14 cm a 3 m). Por eso el sistema fusiona ambas fuentes: cuando hay barrido LIDAR en el ciclo de muestreo, se confía en el rango del rayo más cercano al rumbo de la cámara, y el pinhole queda como respaldo. Su limitación conocida (asume cámara nivelada) está documentada honestamente en `src/python/docs/robot-physical-constants.md`.

#### Raspberry Pi AI HAT+ (26 TOPS)

<p align="center">
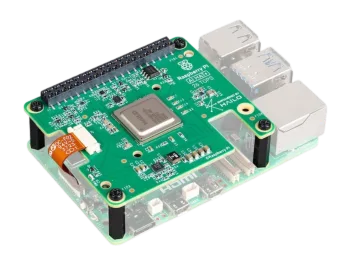
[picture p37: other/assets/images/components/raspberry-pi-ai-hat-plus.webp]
Raspberry Pi AI HAT+ 26 TOPS
	
	<br>
	<i>Raspberry Pi AI HAT+ 26 TOPS</i>
</p>

Si bien la Raspberry Pi 5 es capaz de procesar imágenes en tiempo real, tras algunas pruebas, descubrimos que su tasa de procesamiento era bastante baja (alrededor de 1 a 2 fotos por segundo, con varias optimizaciones implementadas) por ende, tuvimos en cuenta que necesitaba más capacidad de cómputo, por lo cual decidimos incorporar la AI HAT+ a la Raspberry Pi 5 para poder alcanzar el nivel de procesamiento necesario.

El Raspberry Pi AI HAT+ tiene dos versiones, una de 13 billones de operaciones por segundo (TOPS) y otra de 26 TOPS. Como se menciona en el índice, vTitan posee un Raspberry Pi AI HAT+ de 26 TOPS, gracias a este procesador de imágenes, vTitan puede analizar imágenes de 640 px × 640 px a 15 Hz de punta a punta (captura, inferencia y publicación), con el modelo rindiendo 101.5 FPS en inferencia pura. La medición completa está en la [sección del modelo de detección](#modelo-de-detección-yolo).

<table align="center">
<thead>
<tr>
<th align="center"><strong>Medida</strong></th>
<th align="center"><strong>Valor</strong></th>
</tr>
</thead>
<tbody>
<tr>
<td align="center">Largo</td>
<td align="center">65 mm</td>
</tr>
<tr>
<td align="center">Alto</td>
<td align="center">5.5 mm</td>
</tr>
<tr>
<td align="center">Ancho</td>
<td align="center">56 mm</td>
</tr>
<tr>
<td align="center">Peso</td>
<td align="center">9.07 g</td>
</tr>
</tbody>
</table>

#### Raspberry Pi Zero 2 W

<p align="center">
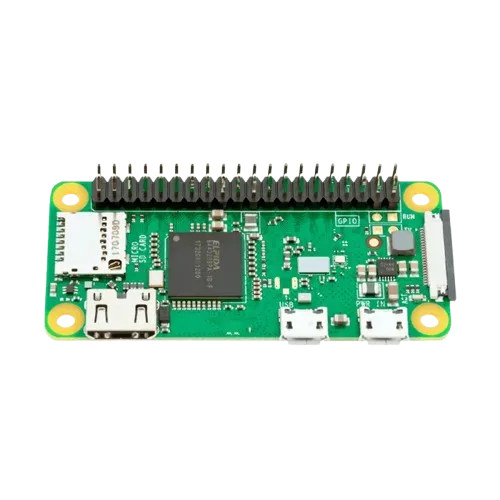
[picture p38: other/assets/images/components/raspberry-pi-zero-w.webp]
Raspberry Pi Zero 2 W
	
	<br>
	<i>Raspberry Pi Zero 2 W</i>
</p>

Construida sobre el chip Broadcom BCM2710A1 de cuatro núcleos, la Raspberry Pi Zero 2 W es un ordenador de placa única ligero y ultra compacto para vTitan. Al ejecutar un entorno Linux completo, este chip permite una fácil integración con el resto de los componentes Raspberry, haciendo que establecer comunicación de red o serial con una Raspberry Pi 5 sea nativo y sencillo dentro del mismo ecosistema.

Además de ofrecer cuatro núcleos a 1 GHz, supera drásticamente la capacidad de procesamiento de microcontroladores de tamaño similar, como el Arduino Nano que cuenta con una frecuencia de 16 MHz a 20 MHz.

Incorpora conectividad Wi-Fi/Bluetooth y regletas de pines GPIO soldadas. Esto ofrece una gran ventaja a la hora de desarrollar y practicar, ya que permite monitorear exactamente qué está procesando vTitan en tiempo real a través de la red, sin necesidad de utilizar LED de distintos colores para señalizar decisiones y logrando un acabado final mucho más limpio.

<table align="center">
<thead>
<tr>
<th align="center"><strong>Medida</strong></th>
<th align="center"><strong>Valor</strong></th>
</tr>
</thead>
<tbody>
<tr>
<td align="center">Largo</td>
<td align="center">65 mm</td>
</tr>
<tr>
<td align="center">Alto</td>
<td align="center">13 mm</td>
</tr>
<tr>
<td align="center">Ancho</td>
<td align="center">30 mm</td>
</tr>
<tr>
<td align="center">Peso</td>
<td align="center">12 g</td>
</tr>
</tbody>
</table>

#### RPLiDAR C1

<p align="center">
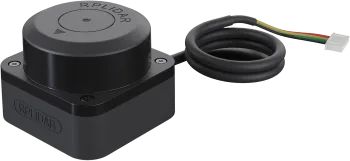
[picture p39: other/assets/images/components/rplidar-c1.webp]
RPLiDAR C1
	
	<br>
	<i>RPLiDAR C1</i>
</p>

El RPLiDAR C1 es un escáner de rango láser de 360 grados, el cual puede detectar superficies que están hasta 12 metros de distancia, su punto ciego es de tan solo 5 centímetros alrededor del mismo, todos estos factores hacen que el RPLiDAR C1 sea una gran opción para poder guiar a vTitan por la pista.

Este RPLiDAR C1 permite a vTitan poder identificar exactamente dónde está ubicado en la pista, gracias a que nos ofrece 230° continuos de visión hacia el frente y los costados, suficientes para navegar la pista con autonomía, la prioridad para el uso apropiado de este sensor, en el caso de la categoría Futuros Ingenieros es montarlo con su plano de barrido por debajo de los 10 cm sobre el suelo, para que alcance tanto las paredes como los bloques; lo más adelantado posible; y sin nada que lo tape.

<table align="center">
<thead>
<tr>
<th align="center"><strong>Medida</strong></th>
<th align="center"><strong>Valor</strong></th>
</tr>
</thead>
<tbody>
<tr>
<td align="center">Largo</td>
<td align="center">55.6 mm</td>
</tr>
<tr>
<td align="center">Alto</td>
<td align="center">41.3 mm</td>
</tr>
<tr>
<td align="center">Ancho</td>
<td align="center">55.6 mm</td>
</tr>
<tr>
<td align="center">Peso</td>
<td align="center">110 g</td>
</tr>
</tbody>
</table>

Especificaciones técnicas:

<table align="center">
<thead>
<tr>
<th align="center"><strong>Especificación</strong></th>
<th align="center"><strong>Valor</strong></th>
</tr>
</thead>
<tbody>
<tr>
<td align="center">Rango de distancia</td>
<td align="center">Blanco: 0.05-12 m (70% de reflectividad); Negro: 0.05-6 m (10% de reflectividad)</td>
</tr>
<tr>
<td align="center">Frecuencia de muestreo</td>
<td align="center">5 kHz</td>
</tr>
<tr>
<td align="center">Resolución angular</td>
<td align="center">0.72°</td>
</tr>
<tr>
<td align="center">Ángulo de inclinación</td>
<td align="center">0°-1.5°</td>
</tr>
</tbody>
</table>

#### Servomotor Hiwonder HPS-3527SG (35 kg·cm)

<p align="center">
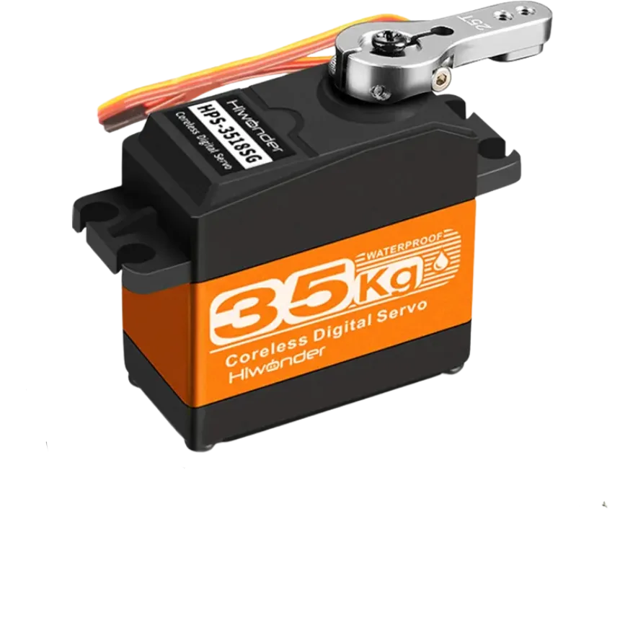
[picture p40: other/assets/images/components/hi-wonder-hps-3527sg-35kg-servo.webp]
Servomotor Hiwonder HPS-3527SG
	
	<br>
	<i>Servomotor Hiwonder HPS-3527SG</i>
</p>

El Hiwonder HPS-3527SG es el servomotor que controla la dirección de vTitan. Lo elegimos por combinar tres cosas en un encapsulado pequeño y ligero: los 35 kg·cm de par que exige mover cuatro ruedas motrices en contrafase, un recorrido de 270° y una precisión de posicionamiento más que suficiente para la pista.

Lo gobernamos con la biblioteca `adafruit_motor` y su módulo `servo`, que traduce el ángulo que pedimos al ancho de pulso correspondiente. Eso deja el código de dirección legible sin coste de rendimiento.

<table align="center">
<thead>
<tr>
<th align="center"><strong>Medida</strong></th>
<th align="center"><strong>Valor</strong></th>
</tr>
</thead>
<tbody>
<tr>
<td align="center">Largo</td>
<td align="center">40 mm</td>
</tr>
<tr>
<td align="center">Alto</td>
<td align="center">28.8 mm</td>
</tr>
<tr>
<td align="center">Ancho</td>
<td align="center">20 mm</td>
</tr>
<tr>
<td align="center">Peso</td>
<td align="center">50 g</td>
</tr>
</tbody>
</table>

#### REV HD Hex Motor

<p align="center">
	HD Hex Motor
	<br>
	<i>HD Hex Motor</i>
</p>

Después de probar distintos modelos de motor optamos por el REV HD Hex Motor, porque cumple los dos requisitos que buscábamos: encoder integrado y un régimen de giro alto (6000 rpm sin carga). El torque de bloqueo no fue el criterio decisivo, porque la reducción total de 3.29 de nuestra transmisión lo multiplica (ver [Relación de Torque y Velocidad](#relación-de-torque-y-velocidad)); lo que descartó al motor anterior fue no dar torque suficiente ni siquiera montado en esa misma transmisión. A esto se sumó que encajaba con facilidad en el chasis que ya teníamos diseñado: solo hubo que rehacer su encaje.

<table align="center">
<thead>
<tr>
<th align="center"><strong>Medida</strong></th>
<th align="center"><strong>Valor</strong></th>
</tr>
</thead>
<tbody>
<tr>
<td align="center">Largo</td>
<td align="center">77 mm</td>
</tr>
<tr>
<td align="center">Diámetro</td>
<td align="center">37 mm</td>
</tr>
<tr>
<td align="center">Peso</td>
<td align="center">234 g</td>
</tr>
</tbody>
</table>

#### IMU GY-BNO085

<p align="center">
	Giroscopio BNO085
	<br>
	<i>Giroscopio BNO085</i>
</p>

El GY-BNO085 es nuestro sensor de orientación inercial (IMU). Lo usamos para que el robot mantenga rumbo en los cruces y cuente las vueltas dadas tanto en el Open Challenge como en el Obstacle Challenge, aunque exista algún problema mecánico que lo desvíe de su trayectoria.

**Cómo lo usamos (y cómo no).** El BNO085 no alimenta un PID de rumbo: alimenta la **pose**. Corre en modo UART-RVC a 100 Hz, una fusión interna de 6 ejes (giroscopio + acelerómetro, sin magnetómetro) que el chip calcula por sí mismo. Elegimos descartar el magnetómetro a propósito: sobre la pista conviven tres motores, un chasis metálico y la electrónica de potencia, y un rumbo por campo magnético sería vulnerable a todo eso. La contrapartida es la deriva de la hoja de datos (~0.5°/min), que acotamos por otras vías (ver abajo). Esta decisión, con su comparación cuantitativa contra el modo de 9 ejes, está documentada en `other/docs/adr/0079-imu-6axis-and-yaw-reference.md`.

**Calibración y referencia de rumbo.** El modo RVC no expone rutinas de calibración al usuario: la calibración de giroscopio/acelerómetro la hace el chip en su arranque. Nuestra parte del proceso es la **referencia de yaw**, y es deliberadamente simple:

1. El robot se enciende y se coloca en la pose de salida (puede quedar girado 90° o 180° respecto al pasillo; es irrelevante).
2. Al presionar el botón de inicio, el estimador fija un desplazamiento (offset): ese rumbo pasa a ser 0°. Todo el yaw del robot es relativo a esa referencia (`reset_heading_reference` en `src/python/src/state_machine/estimator.py`).
3. Durante la ronda, la deriva se acota con un filtro complementario contra el mundo «Manhattan» de la pista: cada pared es paralela o perpendicular al pasillo, así que el promedio circular de los ángulos medidos por el LIDAR recupera el rumbo absoluto y corrige la deriva del IMU.

La implementación maneja dos variables: `yaw_deg` (orientación relativa desde el inicio de la ronda) y `relative_yaw`, que acumula las vueltas sin saltar en ±180°. Dividiendo `relative_yaw` entre 90 y redondeando hacia abajo sabemos cuántos tramos rectos recorrió; cuando el cociente llega a ±12, el robot sabe que está en su zona de estacionamiento y avanza un poco más hasta detenerse (en el Open Challenge).

<table align="center">
<thead>
<tr>
<th align="center"><strong>Medida</strong></th>
<th align="center"><strong>Valor</strong></th>
</tr>
</thead>
<tbody>
<tr>
<td align="center">Largo</td>
<td align="center">25.6 mm</td>
</tr>
<tr>
<td align="center">Alto</td>
<td align="center">22.7 mm</td>
</tr>
<tr>
<td align="center">Ancho</td>
<td align="center">4.6 mm</td>
</tr>
<tr>
<td align="center">Peso</td>
<td align="center">3 g</td>
</tr>
</tbody>
</table>

#### Batería Li-Po Ovonic Air de 11.1 V

<p align="center">
	Ovonic Air 11.1V Li-Po Battery
	<br>
	<i>Ovonic Air 11.1V Li-Po Battery</i>
</p>

La batería de 11.1 V de la marca Ovonic es la fuente de alimentación principal: de ella se alimentan la Raspberry Pi 5 y todos sus componentes embebidos, además del motor de tracción. Usamos **dos modelos de la misma serie 3S**, con un rol distinto cada uno:

<table align="center">
<thead>
<tr>
<th align="center"><strong>Característica</strong></th>
<th align="center"><strong>Competencia: Ovonic 3S Short 2200 mAh 120C</strong></th>
<th align="center"><strong>Prácticas: Ovonic 3S 3000 mAh 50C</strong></th>
</tr>
</thead>
<tbody>
<tr>
<td align="center">Voltaje nominal</td>
<td align="center">11.1 V (3S1P, celdas 3.8-4.2 V)</td>
<td align="center">11.1 V (3S)</td>
</tr>
<tr>
<td align="center">Capacidad</td>
<td align="center">2200 mAh (24.4 Wh)</td>
<td align="center">3000 mAh (33.3 Wh)</td>
</tr>
<tr>
<td align="center">C-rating</td>
<td align="center">120C</td>
<td align="center">50C</td>
</tr>
<tr>
<td align="center">Conector</td>
<td align="center">XT60</td>
<td align="center">Deans (T-plug)</td>
</tr>
<tr>
<td align="center">Dimensiones</td>
<td align="center">77.17 × 34.06 × 25.12 mm</td>
<td align="center">107 × 24 × 33 mm</td>
</tr>
<tr>
<td align="center">Peso</td>
<td align="center">140 g</td>
<td align="center">186 g</td>
</tr>
</tbody>
</table>

**Por qué dos.** La de 3000 mAh/50C es la batería de **prácticas**: más capacidad para sesiones largas de calibración y depuración sin recargas, a cambio de más peso y volumen. La de 2200 mAh/120C es la de **competencia**, en formato compacto («shorty») y con conector XT60: menos capacidad, pero 46 g menos en la balanza (140 g contra 186 g) y un C-rating doble, que es lo que importa en pista.

**Por qué es suficiente.** El presupuesto de potencia del robot (ver la [sección de consumo energético](#consumo-energético)) da un total nominal de ~14-16 A y picos de ~31 A, de los cuales la rama de tracción - el motor al 50% del ciclo de trabajo - aporta ~10 A nominales y ~20 A de pico, y el resto del sistema ~4-6 A. Con la batería de competencia:

- **Autonomía**: 2200 mAh contra ~14 A nominales sostenidos da ~9 minutos de operación continua a plena demanda. Una ronda completa dura pocos minutos y la tracción no exige su nominal el 100% del tiempo, así que el margen real es mayor; el límite práctico en un día de competencia no es la descarga de una ronda sino el ciclo de recargas entre rondas.
- **Corriente de pico**: el C-rating de 120C anunciado representa 264 A, cifra de marketing en condiciones ideales; incluso descontando la mitad por realismo continuo, la batería puede entregar más de 100 A, más de 3 veces el pico de ~31 A del presupuesto completo. La entrega de corriente no es el cuello de botella en ninguna parte del sistema.

Usar baterías más pequeñas no tiene sentido (el margen energético ya es holgado), y usar la de prácticas en competencia solo pagaría el peso y el volumen extra de una batería más grande, sin ningún beneficio en pista.

<table align="center">
<thead>
<tr>
<th align="center"><strong>Medida</strong></th>
<th align="center"><strong>Valor</strong></th>
</tr>
</thead>
<tbody>
<tr>
<td align="center">Largo</td>
<td align="center">107 mm</td>
</tr>
<tr>
<td align="center">Alto</td>
<td align="center">24 mm</td>
</tr>
<tr>
<td align="center">Ancho</td>
<td align="center">33 mm</td>
</tr>
<tr>
<td align="center">Peso (medido, con conectores Deans)</td>
<td align="center">190 g</td>
</tr>
</tbody>
</table>

> Las medidas son de la batería de prácticas; el peso medido con conectores (190 g) sobre el listado de 186 g explica la diferencia entre ambas cifras.

#### Puente H BTS7960 / IBT-2

<p align="center">
	Puente H BTS7960 / IBT-2
	<br>
	<i>Puente H BTS7960 / IBT-2 (el que monta vTitan actualmente)</i>
</p>

El BTS7960 es el puente H que controla el motor de tracción. **No fue nuestra primera opción: reemplazó al L298N, y el motivo fue puramente de corriente.**

<p align="center">
	Puente H L298N
	<br>
	<i>Puente H L298N - el diseño anterior, descartado por corriente insuficiente</i>
</p>

El L298N entrega **2 A por canal**. Cuando pasamos a medir realmente lo que consume el tren motriz con el motor actual, los números no cuadraban: la rama de tracción consume del orden de **10 A promedio** al 50% del ciclo de trabajo, con **picos instantáneos cercanos a 20 A** en los arranques y en los cambios de sentido. Eso es un orden de magnitud por encima de lo que el L298N puede sostener, y explicaba los cortes y el calentamiento que veíamos: el puente no estaba fallando, estaba operando muy por encima de su especificación.

El BTS7960 está clasificado a **43 A**, lo que deja un margen amplio incluso sobre los picos. La otra diferencia importante es la caída de tensión: el L298N usa transistores bipolares y pierde cerca de 2 V en el puente, mientras que el BTS7960 usa MOSFET y esa pérdida es mucho menor, de modo que llega más tensión útil al motor con la misma batería.

Este cambio también reordenó el análisis del resto de la ruta de potencia. Con el puente sobredimensionado, **el elemento más débil pasó a ser el interruptor de encendido**, cuya capacidad de conducción continua está muy por debajo del BTS7960 y de lo que puede entregar la batería. Lo dejamos documentado en el esquemático como el punto a vigilar, porque un componente sobredimensionado no elimina un cuello de botella: solo lo mueve de sitio.

> [!WARNING]
> **Pendiente declarado.** No hemos medido la capacidad de conducción continua del interruptor, así que el margen de esa rama es el único del presupuesto eléctrico que damos por cualitativo.

<table align="center">
<thead>
<tr>
<th align="center"><strong>Característica</strong></th>
<th align="center"><strong>L298N (anterior)</strong></th>
<th align="center"><strong>BTS7960 (actual)</strong></th>
</tr>
</thead>
<tbody>
<tr>
<td align="center">Corriente máxima</td>
<td align="center">2 A por canal</td>
<td align="center">43 A</td>
</tr>
<tr>
<td align="center">Tecnología</td>
<td align="center">Transistor bipolar</td>
<td align="center">MOSFET</td>
</tr>
<tr>
<td align="center">Caída en el puente</td>
<td align="center">~2 V</td>
<td align="center">Muy baja</td>
</tr>
<tr>
<td align="center">Control</td>
<td align="center">ENA + IN1/IN2</td>
<td align="center">RPWM / LPWM independientes</td>
</tr>
</tbody>
</table>

#### Step Down Mini-560 Pro

<p align="center">
	Step Down Mini-560 Pro
	<br>
	<i>Step Down Mini-560 Pro (el que monta vTitan actualmente)</i>
</p>

El Mini-560 Pro es el regulador que alimenta el riel propio del servo de dirección, separándolo del riel de 5V de la Raspberry Pi para que los picos de corriente del servo no lleguen al computador.

<p align="center">
	Step Down XLC4016
	<br>
	<i>Step Down XLC4016 - el regulador anterior, descartado por peso</i>
</p>

**También es un reemplazo, y aquí el criterio fue el peso.** El regulador original era un XLC4016, un módulo notablemente más grande y pesado. El peso fue un problema recurrente en nuestros prototipos (llegamos a estar 200 gramos por encima del límite), así que revisamos la lista de componentes buscando piezas que estuvieran sobredimensionadas para su función. El regulador del servo era una de ellas: la corriente que realmente necesita esa rama es muy inferior a lo que el XLC4016 podía entregar, de modo que estábamos pagando peso por una capacidad que nunca íbamos a usar.

El Mini-560 Pro cubre la demanda real del servo en un encapsulado mucho más compacto. La diferencia medida es de **24 g a 5 g: 19 gramos menos, casi un 80% del peso del módulo anterior**, por una capacidad que la rama del servo no necesitaba.

<table align="center">
<thead>
<tr>
<th align="center"><strong>Regulador</strong></th>
<th align="center"><strong>Peso</strong></th>
</tr>
</thead>
<tbody>
<tr>
<td align="center">XLC4016 (anterior)</td>
<td align="center">24 g</td>
</tr>
<tr>
<td align="center">Mini-560 Pro (actual)</td>
<td align="center">5 g</td>
</tr>
<tr>
<td align="center"><strong>Diferencia</strong></td>
<td align="center"><strong>-19 g</strong></td>
</tr>
</tbody>
</table>

Diecinueve gramos no ganan una carrera por sí solos, y ese es justamente el punto: **el peso no se recupera de un solo golpe, sino sumando decisiones pequeñas**. Llegamos a estar 200 g por encima del límite, y ninguna pieza individual explicaba esos 200 g. Resolver eso consistió en repetir este mismo ejercicio pieza por pieza (¿cuánta capacidad usa realmente esta rama, y cuánto peso estamos pagando por la que sobra?). Es el mismo razonamiento que aplicamos en la transmisión y en el chasis: **dimensionar cada pieza contra la carga medida, no contra el peor caso imaginable.**

#### Pantalla OLED SSD1306

<p align="center">
	SSD1306 OLED Display
	<br>
	<i>SSD1306 OLED Display 128x64</i>
</p>

Pantalla monocroma de 128x64 píxeles conectada por I2C. Cumple una función de diagnóstico en pista: muestra el estado de la máquina de estados, el desafío seleccionado por el puente físico (jumper) y el resultado del autodiagnóstico de arranque, sin necesidad de conectar un computador ni depender de la red. En una mesa de competencia, poder leer en qué estado está el robot antes de pulsar el botón de inicio evita arrancar una ronda con un sensor caído.

#### Convertidor KL89576 (DC a USB-C)

Convertidor reductor que toma la tensión de la batería y entrega **5 V a 5 A por salida USB-C**, dedicado exclusivamente a la Raspberry Pi 5. Es una rama independiente de la del servo y la del motor: las tres cuelgan de la batería por separado, de modo que el consumo del tren motriz no puede provocar una caída de tensión en el computador y reiniciarlo a mitad de una ronda.

El dimensionamiento merece una aclaración, porque la tabla de consumo suma por componente y aquí esa suma sería engañosa. El AI HAT+, la cámara, el LIDAR y el puente IMU no se alimentan del KL89576 directamente: se alimentan del riel de 5 V de la propia Pi 5, y la Pi Zero entera (motor, adaptador de nivel, OLED, encoder) recibe su alimentación por el VBUS del puerto USB de la Pi 5. Es decir, los 5 A de la especificación de la Pi 5 **ya incluyen** a todo lo conectado a la placa, y el pico del AI HAT+ (2.5 A) no se suma dos veces. El presupuesto real de la rama es: pico de la placa con sus periféricos (5 A, valor de especificación oficial que cubre el AI HAT+) más LIDAR (0.6 A) e IMU (0.03 A), ambos casi constantes, contra los 5 A del convertidor.

Ese margen es deliberadamente fino y lo monitoreamos en vez de sobredimensionarlo sin medir: el indicador `vcgencmd get_throttled` de la Pi 5 reporta cualquier caída de tensión, y es la misma señal con la que verificamos (0x0, sin eventos) que la Pi Zero alimentada por VBUS funciona sin caída de tensión (undervoltage) en carrera. Si el margen algún día se cerrara, el punto de vigilancia es el consumo conjunto placa+NPU, no el convertidor.

### Diagrama de conexiones

El arnés completo de vTitan está trazado como un esquemático generado por código, no dibujado a mano: la fuente reside en [`schemes/wiring/tscircuit/circuit.tsx`](schemes/wiring/tscircuit/circuit.tsx) y se exporta con [tscircuit](https://tscircuit.com/). Esto nos permite versionar el cableado igual que el resto del código: cualquier cambio de pin queda en el historial de git y el render se regenera desde la misma fuente.

<p align="center">
    Diagrama de conexiones de vTitan
    <br>
    <i>Arnés de conexiones de vTitan - <a href="schemes/wiring/harness.schematic.png">versión PNG</a></i>
</p>

Para regenerar los artefactos tras editar `circuit.tsx`:

```bash
cd schemes/wiring/tscircuit
npm install
npm run artifacts   # netlist legible + SVG (fondo blanco) + PNG a 2400 px
```

Los exportados (`harness.schematic.svg` y `harness.schematic.png`) se versionan en `schemes/wiring/`, ya que son lo que se lee en esta documentación y reconstruirlos exige toda la cadena de herramientas de tscircuit.

### Consumo energético

<table align="center">
<thead>
<tr>
<th align="center"><strong>Componente</strong></th>
<th align="center"><strong>Cantidad</strong></th>
<th align="center"><strong>Voltaje</strong></th>
<th align="center"><strong>Corriente sin carga</strong></th>
<th align="center"><strong>Corriente Nominal</strong></th>
<th align="center"><strong>Corriente Pico</strong></th>
</tr>
</thead>
<tbody>
<tr>
<td align="center">Raspberry Pi 5</td>
<td align="center">1</td>
<td align="center">5.0V</td>
<td align="center">~0.50A</td>
<td align="center">~1.50A - 2.50A</td>
<td align="center">5.00A</td>
</tr>
<tr>
<td align="center">Raspberry Pi Zero 2 W</td>
<td align="center">1</td>
<td align="center">5.0V</td>
<td align="center">~0.10A</td>
<td align="center">~0.35A - 0.50A</td>
<td align="center">0.70A</td>
</tr>
<tr>
<td align="center">Raspberry Pi Camera Module 3 Wide</td>
<td align="center">1</td>
<td align="center">3.3V</td>
<td align="center">~0.05A</td>
<td align="center">~0.25A</td>
<td align="center">0.30A</td>
</tr>
<tr>
<td align="center">Raspberry Pi AI HAT+ (26 TOPS)</td>
<td align="center">1</td>
<td align="center">5.0V</td>
<td align="center">~0.10A</td>
<td align="center">~1.00A - 1.50A</td>
<td align="center">2.50A</td>
</tr>
<tr>
<td align="center">RPLiDAR C1</td>
<td align="center">1</td>
<td align="center">5.0V</td>
<td align="center">~0.20A</td>
<td align="center">~0.40A</td>
<td align="center">0.60A</td>
</tr>
<tr>
<td align="center">Hiwonder HPS-3527SG 35 kg Servo</td>
<td align="center">1</td>
<td align="center">4.8V - 8.4V</td>
<td align="center">~0.02A</td>
<td align="center">~0.30A - 0.50A</td>
<td align="center">1.80A (Stall)</td>
</tr>
<tr>
<td align="center">IMU GY-BNO085 (6 ejes en modo RVC)</td>
<td align="center">1</td>
<td align="center">3.3V - 5.0V</td>
<td align="center">~0.003A</td>
<td align="center">~0.015A</td>
<td align="center">0.03A</td>
</tr>
<tr>
<td align="center">Puente H BTS7960 / IBT-2</td>
<td align="center">1</td>
<td align="center">5V / 6-27V</td>
<td align="center">~0.007A (Lógica)</td>
<td align="center">~10.00A (tracción)</td>
<td align="center">~20.00A (picos)</td>
</tr>
<tr>
<td align="center"><strong>TOTAL</strong></td>
<td align="center"><strong>8</strong></td>
<td align="center"><strong>3.3V-5V</strong></td>
<td align="center"><strong>~0.980A</strong></td>
<td align="center"><strong>~13.82A - 15.67A</strong></td>
<td align="center"><strong>~30.93A</strong></td>
</tr>
</tbody>
</table>

> [!NOTE]
> Tres aclaraciones sobre esta tabla:
>
> - **Rama de tracción.** El salto respecto de versiones anteriores no es un cambio de consumo del robot, sino una corrección: el puente anterior figuraba con «según motor» en la columna nominal, de modo que la corriente de tracción, que es la mayor del sistema con diferencia, nunca entraba en el total. Los ~10 A nominales y ~20 A de pico son la rama del motor medida al 50% del ciclo de trabajo, y son exactamente el motivo por el que el L298N de 2 A por canal tuvo que ser reemplazado. El valor de 43 A del BTS7960 es la clasificación de la pieza, no un consumo: no se suma aquí.
> - **Rama del computador.** Los picos de la Raspberry Pi 5 (5.00 A) y del AI HAT+ (2.50 A) **no se suman**: el AI HAT+ se alimenta del riel de 5 V de la propia Pi 5, y el pico de 5 A de la placa ya cubre por especificación a todo lo conectado a ella, incluida la Pi Zero, que recibe su alimentación por el VBUS de un puerto USB de la Pi 5. Los 5 A del KL89576 dimensionan esta rama completa; ver la [sección del convertidor](#convertidor-kl89576-dc-a-usb-c).
> - **Tres ramas separadas.** Computador, servo y tracción se alimentan de la batería por separado a propósito. El total sirve para dimensionar la batería y el interruptor, no para dimensionar un único regulador.

<!-- HUECO (rubro WRO 2026, criterio 2 "modos de fallo y fiabilidad").
Falta la sección de protección eléctrica: fusible o limitador en la rama de
tracción (picos medidos de ~20 A), corte por bajo voltaje de la Li-Po 3S, y
procedimiento de carga y almacenamiento. (La discrepancia de la altura del haz
del LIDAR quedó resuelta: 0.08 m, ver ADR 0014.) -->

### Calibración

Cada sensor del robot tiene una parte calibrada contra medición propia, no contra la hoja de datos. Este es el inventario:

| Qué | Método | Valor |
|-----|---|---|
| Pulsos por vuelta del encoder | Cinta métrica: distancia conocida recorrida contra la que el robot cree haber recorrido (`task robot:calibrate-encoder`) | 60 pulsos/vuelta en el HD Hex. Se heredó el 676 del motor retirado, se midió 86 y se corrigió a 60 |
| Ley motor-duty en banco | Motor cargado, duty barrido, rpm medidas contra cinta | $\text{rpm} = 434.6 \cdot \text{duty} - 86.7$ ($R^2 = 0.9999$); zona muerta en duty 0.200 |
| Referencia de yaw del IMU | Reinicio del desplazamiento (offset) al presionar el botón de inicio: ese rumbo pasa a ser 0° (`reset_heading_reference`) | Todo el yaw de la ronda es relativo a esa referencia |
| Calibración giroscopio/acelerómetro | Rutina del chip (modo RVC) en su arranque; no intervenimos | De fábrica |
| Latencia cámara→detección | Medida de punta a punta sobre bags reales | **0.85 s** (ejecuciones del 2026-09-06); el rango LIDAR del ciclo actual cubre el hueco |
| Rango de la visión | Modelo pinhole contra barrido LIDAR: cuando hay medición LIDAR al rumbo de la cámara, manda el LIDAR; el pinhole queda de respaldo | Error del pinhole: ~3.6 cm a 1.5 m, ~14 cm a 3 m |
| Radio de giro del chasis | Medido en banco | 0.29 m, usado como límite duro en simulación y control |
| Simulador | Ajustado contra grabaciones reales; conclusiones previas a la calibración descartadas | Ver [Simulador y corpus de escenarios](#simulador-y-corpus-de-escenarios) |

La consecuencia de método: ninguna constante del robot es un número «de fábrica» sin justificación; cada una de estas mediciones tiene una historia de hallazgo documentada en la [sección de hallazgos](#hallazgos-de-ingeniería).

## Arquitectura de software

Esta sección describe el software que corre a bordo: cómo se reparte entre las dos placas, el detector de señales y los lazos de control.

### Arquitectura ROS2 y reparto entre dos computadores

vTitan no corre sobre un solo computador, sino sobre dos, y el reparto no es por comodidad: es la decisión de arquitectura que sostiene todo lo demás.

La **Raspberry Pi 5** se encarga de percepción y planificación (LIDAR, cámara, inferencia en el AI HAT+, decidir hacia dónde ir), y la **Raspberry Pi Zero 2 W** se encarga exclusivamente del control en tiempo real del motor y del servo. El motivo es que esas dos cargas tienen exigencias temporales incompatibles. La inferencia de visión es pesada y su tiempo de respuesta varía; el lazo de control del motor tiene que ejecutarse a ritmo constante o el robot se vuelve inestable. Si ambas cosas compiten por el mismo procesador, un fotograma lento se traduce en una corrección de dirección tardía. Separándolas, **ningún retraso de visión puede detener el lazo de control**.

El software está organizado en cinco paquetes ROS2:

<table align="center">
<thead>
<tr>
<th align="left">Paquete</th>
<th align="left">Responsabilidad</th>
</tr>
</thead>
<tbody>
<tr>
<td align="left"><code>vtitan_bringup</code></td>
<td align="left">Lanzamiento del sistema completo y composición de nodos</td>
</tr>
<tr>
<td align="left"><code>vtitan_drivers</code></td>
<td align="left">Controladores de hardware: IMU, I2C, UART</td>
</tr>
<tr>
<td align="left"><code>vtitan_navigation</code></td>
<td align="left">Navegación: seguimiento de pasillo, planificación, escapes</td>
</tr>
<tr>
<td align="left"><code>vtitan_state_machine</code></td>
<td align="left">Máquina de estados de carrera y grabación de bags</td>
</tr>
<tr>
<td align="left"><code>vtitan_vision</code></td>
<td align="left">Cámara e inferencia de detección</td>
</tr>
</tbody>
</table>

Visto como componentes, el reparto queda así. `vtitan_bringup` es la única caja que no participa en la comunicación: no declara ningún ejecutable, solo los archivos de lanzamiento que arrancan a las demás.

<!-- mermaid-src: schemes/flowcharts/common/mermaid/paquetes-ros2.mmd -->
```mermaid
flowchart LR
    subgraph PI5["RASPBERRY PI 5 - percepción y planificación"]
        VIS["vtitan_vision<br/>cámara + inferencia Hailo<br/>1 nodo"]
        NAV["vtitan_navigation<br/>pasillo, plan, escapes<br/>1 nodo"]
        SM["vtitan_state_machine<br/>estados, bags, telemetría<br/>3 nodos"]
        IMUP["vtitan_drivers (IMU)<br/>BNO085 UART-RVC"]
        LID["sllidar_ros2<br/>paquete de terceros"]
    end

    subgraph ZERO["RASPBERRY PI ZERO 2 W - control en tiempo real"]
        MOT["vtitan_drivers (motores)<br/>ackermann_motor_node<br/>proceso propio"]
        PER["vtitan_drivers (periféricos)<br/>botón + OLED + jumper<br/>un solo proceso"]
    end

    BRING["vtitan_bringup<br/>solo launch files, sin ejecutables"]

    BRING -.->|lanza| PI5
    BRING -.->|lanza| ZERO

    LID -->|"/scan"| NAV
    VIS -->|"/vision/detections"| NAV
    IMUP -->|"/imu/data"| NAV
    MOT -->|"/joint_states"| NAV
    NAV -->|"/ackermann_cmd"| MOT

    SM <-->|"estado, modo, vueltas"| NAV
    SM <-->|"estado, botón, jumper"| PER

    classDef externo stroke:#6e7781,stroke-dasharray: 4 3
    class LID externo
```

Los nodos se comunican por **29 tópicos (topics) declarados en un único archivo de configuración** (`ros_topics.toml`) en lugar de estar escritos a mano en cada nodo. Esto evita una clase de error entera: un nodo que publica en `/lidar/scan` mientras otro escucha `/scan` compila, arranca y no funciona, sin ningún mensaje de error. Con los nombres centralizados, esa discrepancia no puede existir.

Bajando al detalle, el grafo se parte en dos planos casi disjuntos. El **plano de carrera** es el que decide y actúa, y es el único que cruza la frontera entre las dos placas: solo dos tópicos la atraviesan en el lazo cerrado, `/ackermann_cmd` de ida y `/joint_states` de vuelta. Cada flecha sale de un `create_publisher`/`create_subscription` real del código, no de una descripción escrita a mano:

<!-- mermaid-src: schemes/flowcharts/common/mermaid/nodos-ros2.mmd -->
```mermaid
flowchart LR
    subgraph PI5["RASPBERRY PI 5 - percepción y planificación"]
        LIDAR(["sllidar_node<br/>(sllidar_ros2)"])
        IMU(["imu<br/>bno08x_uart_rvc_node"])
        VISION(["vision<br/>vision_node"])
        NAVE(["track_navigator<br/>track_navigator_node"])
        SMN(["state_machine<br/>state_machine_node"])
    end

    subgraph ZERO["RASPBERRY PI ZERO 2 W - control en tiempo real"]
        MOTOR(["ackermann_motor_node"])
        BTN(["button_node"])
        CHAL(["challenge_mode_node"])
    end

    LIDAR -->|"/scan"| NAVE
    LIDAR -->|"/scan"| VISION
    IMU -->|"/imu/data"| NAVE
    VISION -->|"/vision/detections"| NAVE
    NAVE -->|"/nav_debug"| VISION

    NAVE ==>|"/ackermann_cmd"| MOTOR
    MOTOR ==>|"/joint_states"| NAVE

    LIDAR -->|"/scan (vivacidad)"| SMN
    IMU -->|"/imu/data (vivacidad)"| SMN
    VISION -->|"/vision/detections (vivacidad)"| SMN
    NAVE -->|"/race/laps_completed"| SMN
    NAVE -->|"/race/current_corridor"| SMN
    NAVE -->|"/ackermann_cmd"| SMN
    SMN -->|"/robot_state"| NAVE
    SMN -->|"/robot_state"| VISION
    SMN -->|"/challenge_mode/active"| NAVE
    SMN -->|"/challenge_mode/active"| VISION
    SMN -->|"/ackermann_cmd (parada)"| MOTOR

    BTN -->|"/button/event"| SMN
    CHAL -->|"/challenge_mode/jumper_inserted"| SMN

    linkStyle 5,6 stroke-width:3px
```

El **plano de observación** cuelga de los mismos tópicos pero no participa en ninguna decisión: graba los bags, pinta el OLED y agrega las lecturas que este muestra. Es casi enteramente de una dirección, y sus dos únicas vías de vuelta hacia el plano de carrera (el botón remoto y el ajuste de parámetros de visión) son de operador de banco, no de control de carrera:

<!-- mermaid-src: schemes/flowcharts/common/mermaid/nodos-ros2-telemetria.mmd -->
```mermaid
flowchart LR
    subgraph CARRERA["PLANO DE CARRERA (ver nodos-ros2.mmd)"]
        SENS["sllidar_node / imu<br/>/scan, /imu/data"]
        NAVE["track_navigator<br/>/ackermann_cmd, /odom"]
        SMN["state_machine<br/>/robot_state, /race_metrics, /system_status"]
        VISION["vision_node<br/>/vision/detections, /camera/image_raw"]
        MOTOR["ackermann_motor_node<br/>/joint_states, /motor/*"]
        BTN["button_node<br/>/button/hold"]
    end

    subgraph OBS["PLANO DE OBSERVACIÓN"]
        TEL(["telemetry_bridge<br/>telemetry_bridge_node<br/>Pi 5"])
        BAG(["bag_recorder<br/>bag_recorder_node<br/>Pi 5"])
        OLED(["oled_display_node<br/>Pi Zero"])
    end

    SENS -->|"/scan, /imu/data"| TEL
    NAVE -->|"/ackermann_cmd"| TEL
    NAVE -.->|"/odom (clave opcional)"| TEL
    SMN -->|"/robot_state"| TEL
    VISION -->|"/vision/detections"| TEL
    MOTOR -->|"/joint_states"| TEL

    SMN -->|"/robot_state"| BAG
    VISION -->|"/camera/image_raw"| BAG
    BAG -->|"/bag_recorder/run_path"| VISION

    SMN -->|"/robot_state, /race_metrics, /system_status"| OLED
    MOTOR -->|"/motor/drive_speed, /motor/steering_position, /motor/status"| OLED
    BTN -->|"/button/hold"| OLED
    VISION -->|"/system_status (nombre del modelo)"| OLED
    TEL -->|"/ui/telemetry_summary"| OLED
    OLED -->|"/ui/oled_mirror"| SINMIRROR
    SINMIRROR["sin suscriptor en el repo<br/>se lee con ros2 topic echo<br/>o por un puente externo"]

    TEL -.->|"/button/event<br/>botón remoto, solo en banco"| SMN
    TEL -.->|"servicio set_parameters"| VISION

    classDef espejo stroke:#6e7781,stroke-dasharray: 5 4
    class SENS,NAVE,SMN,VISION,MOTOR,BTN espejo
```

En ninguno de los tres diagramas aparece el backend de telemetría en Go. Es deliberado: **en competencia el robot corre sin red**, así que ese enlace no existe durante una ronda, y dibujarlo sugeriría una dependencia que la pista no tiene. `telemetry_bridge_node` sí se queda, porque su salida `/ui/telemetry_summary` es de donde la página RACING del OLED saca las distancias y el yaw. El estado del backend y la política de migración a Go están más abajo, en su propia subsección.

Un detalle que ilustra el nivel de restricción real: el SoC de la Pi Zero 2 W tiene **exactamente dos generadores de PWM por hardware**. Uno está tomado por el servo de dirección, que necesita mantener una posición absoluta y no tolera fluctuaciones. El otro se asigna a la marcha adelante del motor. La marcha atrás, que solo se usa en maniobras de estacionamiento y recuperación a baja velocidad, funciona con PWM por software y sí tolera esa fluctuación. Es un reparto deliberado de un recurso escaso, no una casualidad.
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

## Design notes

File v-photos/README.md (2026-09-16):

# Fotos y renders de vTitan

Carpeta obligatoria de la categoría Futuros Ingenieros. **La descripción del
robot está en el [README principal](../README.md)**; aquí solo está el índice.

```text
v-photos/
├── vtitan/                  vTitan (WRO 2026)
└── klevor/                  Klevor (WRO 2025), cuatro iteraciones
```

## vTitan

| Archivo | Qué es |
|---|---|
| `vtitan-front-view.webp`, `vtitan-rear-view.webp`, `vtitan-left-view.webp`, `vtitan-right-view.webp`, `vtitan-top-view.webp`, `vtitan-bottom-view.webp` | Las seis vistas que pide la categoría |
| `vtitan-full.webp` | Render del conjunto ensamblado desde el CAD |
| `vtitan-breakdown.webp` | Vista despiezada, usada en [Montaje](../README.md#montaje) |
| `vtitan-breakdown-enumerated.webp` | La misma vista despiezada, con cada pieza numerada |

Los renders del conjunto y las dos vistas despiezadas salen del mismo modelo de
SolidWorks del que se exportan [`models/vtitan/`](../models/README.md), así que lo
que se ve en el render es exactamente lo que hay en los `.step` y los `.stl`.

## Prototipos anteriores

`klevor/` guarda las cuatro iteraciones de Klevor, el robot de la
temporada 2025, con sus vistas y (en `klevor-v0.1/`) las tres capas por
separado. Cada iteración tiene su documento con qué cambió y por qué:

- [Klevor v0.1](../other/docs/development/previous-prototypes/klevor-v0.1.md)
- [Klevor v0.1.1](../other/docs/development/previous-prototypes/klevor-v0.1.1.md)
- [Klevor v0.2](../other/docs/development/previous-prototypes/klevor-v0.2.md)
- [Klevor v1.0](../other/docs/development/previous-prototypes/klevor-v1.0.md)

> [!WARNING]
> **Pendiente declarado.** De vTitan solo hay fotos del estado final. La
> historia de iteración documentada con imágenes es la de Klevor, no la de
> vTitan; las fases de diseño de esta temporada están contadas en texto en
> [Evolución y justificación del diseño](../README.md#evolución-y-justificación-del-diseño).

Todas las imágenes están en WebP. `vtitan-full.webp` es la única sin pérdida,
porque es un render del CAD con zonas planas que comprimen bien así; las 45
fotografías usan WebP con pérdida a calidad alta, que en fotos pesa una fracción
de lo que costaría conservarlas sin pérdida.

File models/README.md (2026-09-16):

# Modelos 3D

Piezas de vTitan y de los prototipos anteriores. **El razonamiento de diseño no
vive aquí**: está en el [README principal](../README.md), en
[Movilidad y Diseño Mecánico](../README.md#movilidad-y-diseño-mecánico). Este
documento es el manifiesto: qué hay, en qué formato y para qué sirve cada uno.

```text
models/
├── vtitan/            vTitan (WRO 2026)
│   ├── blueprints/     planos acotados (WebP)
│   ├── step-files/     29 archivos .step  -> para fabricar y editar
│   └── stl-files/      47 archivos .stl   -> para imprimir y para ver en GitHub
└── klevor/            Klevor (WRO 2025)
    ├── blueprints/     27 planos
    └── stl-files/      43 archivos .stl
```

## Por qué dos formatos

| Formato | Para qué | Nota |
|---|---|---|
| **`.step`** | Fabricar y **editar**. Conserva la geometría exacta (B-rep), así que se puede reabrir y modificar en cualquier CAD | GitHub **no** lo previsualiza |
| **`.stl`** | **Imprimir** y **mirar**. Es una malla triangular, no se edita bien, pero es lo que come una impresora 3D | GitHub lo renderiza en un **visor 3D interactivo**: pincha cualquier `.stl` y podrás girarlo, desplazarlo y acercarlo en el navegador |

Por eso publicamos ambos. Si solo quieres ver una pieza, abre el `.stl` desde
GitHub. Si quieres rehacerla, usa el `.step`.

De las 29 piezas en `.step`, **17 tienen su `.stl` con el mismo nombre**. Las 12
restantes son componentes comerciales que modelamos solo para el ensamblaje
virtual y nunca se imprimen: Raspberry Pi 5, cámara, RPLiDAR C1, batería
Ovonic, rodamientos y rolineras (rodamientos pequeños).

## Convención de nombres

Todo en kebab-case ASCII y extensión en minúscula: `pinon-40-dientes-servo-cajera.stl`.
Los nombres originales de SolidWorks (mayúsculas, espacios, `ñ`) se normalizaron
porque rompen URLs, globs de shell y clones en sistemas de archivos que no son
UTF-8. Una pieza que existe en los dos formatos **usa el mismo nombre** en
ambos, que es lo que permite emparejarlas de un vistazo.

### Versiones y variantes

Los sufijos dicen dos cosas distintas, y conviene no confundirlas:

| Sufijo | Significa | Ejemplo |
|---|---|---|
| `-vN` | **Iteración** de la misma pieza. `N` crece con el rediseño y la última es la que se imprime | `monochasis-v1` a `monochasis-v3` |
| `-vN.M` | Retoque menor sobre la `vN`, sin rediseño de fondo | `monochasis-v2.1` (la `v2` aligerada) |
| Sufijo descriptivo | **Variante** que coexiste con la pieza base, no la reemplaza | `pinon-40-dientes-servo-cajera`, `ring-mv-pinon-grande`, `tapa-de-bancada-motor-rev` |

Una variante puede a su vez llevar versión (`brazo-de-tensor-v2-largo` es la
variante larga de la `v2`). Una pieza sin sufijo alguno no tuvo iteraciones.

## Piezas de vTitan, por subsistema

**Transmisión**

`engranaje-unificado-motor-rev-36-dientes`, `engranaje-unificado-motor-rev-40-dientes`,
`pinon-15-dientes-correa-dentada`, `pinon-20-dientes-correa-dentada`,
`pinon-22-dientes-correa-dentada`, `pinon-33-dientes-correa-dentada`,
`pinon-33-dientes-correa-dentada-eje-motor-pequeno`,
`pinon-50-dientes-correa-dentada-eje-motor-pequeno`,
`pinon-40-dientes-transmision`, `pinon-conico-15x8-dientes`,
`pinon-conico-20-dientes`, `pinon-90-cruceta-10-dientes`,
`pinon-90-cruceta-10-dientes-con-eje`, `rueda-dentada`, `rueda-vtitan`,
`ring-mv-v1`, `ring-mv-v2`, `ring-mv-pinon-grande`, `cubierta-de-ring`,
`buje-guia-de-cruceta`, `aro-de-fijacion-axial-de-caucho`

**Dirección**

`brazo-de-direccion`, `pinon-8-dientes-direccion`,
`pinon-20-dientes-direccion-v1`, `pinon-20-dientes-direccion-v2`,
`pinon-20-dientes-rueda-dentada-v1`, `pinon-20-dientes-rueda-dentada-v2`,
`pinon-40-dientes-direccion`, `pinon-40-dientes-direccion-arrastre`,
`pinon-40-dientes-servo`, `pinon-40-dientes-servo-cajera`

**Tensor de correa**

`brazo-de-tensor-v1`, `brazo-de-tensor-v2`, `brazo-de-tensor-v2-largo`,
`brazo-de-tensor-v3`, `rodillo-tensor-v1`, `rodillo-tensor-v2`

**Chasis y bancadas**

`monochasis-v1`, `monochasis-v2`, `monochasis-v2.1`, `monochasis-v3`,
`base-de-sistema-de-transmision-corto`, `soporte-superior`,
`tapa-de-bancada-motor-pequeno`, `tapa-de-bancada-motor-rev`,
`suplemento-de-bancada-motor-pequeno`

**Soportes de cámara**

`soporte-camara-inferior`, `soporte-camara-brazo-intermedio`,
`soporte-camara-superior`

**Componentes comerciales** (modelados solo para el ensamblaje, no se imprimen)

`raspberry-pi-5`, `camera-module-3-v8`, `rplidar-c1`, `ovonic-air-lipo-battery`,
`rodamiento-14-20-12-hk1412`, `rolinera-3-7-2`, `rolinera-6.35-9.525-3.175`

**No son del robot**

`pista-bloque-senales` y `pista-pared-magenta` son piezas de **pista**, no de
vTitan: las señales de color y un tramo de pared que imprimimos para practicar.
`prueba-rodamiento` es una impresión de prueba de ajuste.

## Trazabilidad

Las iteraciones intermedias se conservan a propósito: son la evidencia de cómo
evolucionó el diseño, y esa historia está contada en
[Evolución y justificación del diseño](../README.md#evolución-y-justificación-del-diseño).

Los nombres originales del diseñador (`-max`, `-ultimate`, `-nuevo`, `-editado`,
`-ligero`) se sustituyeron por `-vN` porque no eran ordenables: nada en
`-max` contra `-ultimate` dice cuál vino primero, y el repositorio tampoco lo
sabía, porque las piezas se publicaron todas en el mismo commit. El orden que
recoge la numeración actual es el que confirmó el diseñador.

> [!WARNING]
> **Pendiente declarado.** Falta el manifiesto de impresión: material, altura de
> capa, relleno, soportes y orientación de cama por pieza. Sin esos parámetros,
> otra persona puede abrir los `.stl` pero no reproducir exactamente nuestras
> piezas.

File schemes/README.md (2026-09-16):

# Esquemas y diagramas

Diagramas de flujo, máquinas de estado y el esquemático del arnés. **La
explicación vive en el [README principal](../README.md)**; aquí solo está el
mapa de qué archivo es cada cosa y cómo se regenera.

```text
schemes/
├── ackermann-steering-system.webp      geometría Ackermann (la alternativa que NO usamos)
├── counter-phase-steering-system.webp  dirección en contrafase (la que sí usamos)
├── flowcharts/
│   ├── common/      lógica compartida y arquitectura de software
│   ├── open/        Open Challenge
│   ├── obstacles/   Obstacle Challenge
│   └── _legacy/     diagramas de versiones anteriores, conservados
└── wiring/
    ├── harness.schematic.svg  esquemático del arnés (y su versión .png)
    └── tscircuit/             el proyecto que lo genera
```

## Los diagramas de flujo

Cada diagrama existe **tres veces**, y las tres salen del mismo `.mmd`:

| Dónde | Para qué |
|---|---|
| `flowcharts/<grupo>/mermaid/*.mmd` | **La fuente única.** GitHub la renderiza al abrir el archivo |
| `flowcharts/<grupo>/webp/*.webp` | Render estático, para PDF o para leer sin conexión |
| Bloques ` ```mermaid ` en el README principal | Para que el diagrama se vea sin salir del documento |

`common/` contiene lo que comparten los dos desafíos (inferencia del sentido de
la vuelta, escape ante colisión y atasco, conteo de vueltas, esquiva genérica,
interacciones entre subsistemas). `open/` y `obstacles/` lo **referencian en vez
de redibujarlo**, que es la razón de que exista la separación.

Seis de los diagramas de `common/` no describen comportamiento sino
**estructura**, y conviene leerlos en este orden:

| Archivo | Qué dibuja |
|---|---|
| `subsistemas.mmd` | Hardware: energía y datos entre batería, cómputo, sensores y actuación |
| `paquetes-ros2.mmd` | Los cinco paquetes ROS2 y en qué placa corre cada uno |
| `nodos-ros2.mmd` | Plano de carrera: los 8 nodos que deciden y actúan, tópico a tópico |
| `nodos-ros2-telemetria.mmd` | Plano de observación: bags, OLED y el puente, que solo escuchan |
| `oled-paginas.mmd` | Dentro de `oled_display_node`: la cadena de prioridad que elige la página |
| `oled-fuentes.mmd` | Qué tópico alimenta cada línea de cada página del OLED |

Las aristas de `nodos-ros2*.mmd` salen de un `create_publisher` o
`create_subscription` real, y los nombres de tópico de `src/config/ros_topics.toml`
(la fuente única, ADR 0017). Si se añade o renombra un tópico, esos dos
diagramas son lo que hay que actualizar junto al código. Los dos de `oled-*`
siguen a `vtitan_drivers/oled_display_node.py`: `_update_display` para el árbol
de decisión y los métodos `_render_*` para las líneas de cada página.

Los cinco **solo dibujan lo que corre en competencia**. El backend de telemetría
en Go y su panel quedan fuera a propósito: en pista el robot no tiene red, así
que ese enlace no existe durante una ronda y dibujarlo sugeriría una dependencia
que no hay. Cada `.mmd` lo declara en sus notas `%%`, que no se renderizan.

Las líneas que empiezan por `%%` dentro de un `.mmd` son notas de mantenimiento
(referencias a código, cifras de barridos). No se renderizan nunca y se
descartan al inlinear en el README.

### Regenerar

```bash
task docs:diagrams     # .mmd -> WebP (requiere mermaid-cli vía npx, y cwebp)
task docs:mermaid      # .mmd -> bloques inlineados del README principal
task docs:mermaid -- --check   # falla si algún bloque quedó desincronizado
```

**Si editas un `.mmd`, corre las dos.** La primera actualiza el render, la
segunda la copia del README. `--check` es lo que debería llamar CI para que la
copia no derive nunca de su fuente.

## El arnés

El esquemático de conexiones no está dibujado a mano: se define en código con
[tscircuit](https://tscircuit.com/) en `wiring/tscircuit/circuit.tsx`, así que
un cambio de pin queda en el historial de git como cualquier otro cambio.

```bash
cd schemes/wiring/tscircuit
npm install          # solo la primera vez
npm run artifacts
```

Los exportados (`harness.schematic.svg` y `harness.schematic.png`) se versionan
porque son lo que se lee en la documentación y reconstruirlos exige toda la
cadena de herramientas. El `.png` se conserva como respaldo universal del `.svg`;
esa es la única razón por la que no se convirtió a WebP como el resto.

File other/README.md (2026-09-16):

# `other/` - Todo lo demás

Herramientas, infraestructura y documentación de apoyo que no son material de
competencia. La raíz del repositorio queda con las carpetas obligatorias de la
WRO y con `src/` (el robot); todo lo demás vive aquí dentro.

| Qué | Dónde |
|-----|---|
| Documentación de apoyo (bitácora, documento de ingeniería WRO, guía de las Raspberry Pi) | [`docs/`](docs/) |
| Hojas de datos de los componentes | [`docs/reference/datasheets/`](docs/reference/datasheets/) |
| Historial de prototipos anteriores (Klevor v0.1 a v1.0) | [`docs/development/previous-prototypes/`](docs/development/previous-prototypes/) |
| Entrenamiento, cuantización y compilación del detector YOLO a HEF | [`ml/hailo/`](ml/hailo/) |
| Pesos publicados del detector (ONNX, HEF, PyTorch) | [`ml/weights/`](ml/weights/) |
| Backend de telemetría (Go, HTTP + gRPC) | [`apps/backend/`](apps/backend/) |
| Panel de telemetría (dashboard React + Three.js) | [`apps/frontend/`](apps/frontend/) |
| Simulador Gazebo/ROS2 y generador de escenarios | [`apps/gazebo/`](apps/gazebo/) |
| Auto-annotator: anotación asistida con SAM2 | [`apps/auto-annotator/`](apps/auto-annotator/) |
| Contratos compartidos (protobuf + OpenAPI) consumidos por robot, backend y frontend | [`contracts/`](contracts/) |
| Provisionamiento de las Raspberry Pi con Ansible | [`deploy/ansible/`](deploy/ansible/) |
| Scripts de diagnóstico sobre bags MCAP | [`../src/python/scripts/bag/`](../src/python/scripts/bag/) |
| Salidas de ejecución (bags, fotos, videos); vacía en el repo | [`data/`](data/) |
| Logos e imágenes de la documentación | [`assets/`](assets/) |
| Tareas del Taskfile raíz (fleet, platform, infra) | [`tasks/`](tasks/) y [`../Taskfile.yml`](../Taskfile.yml) |
| Sitio de documentación | [`apps/hugo-docs/`](apps/hugo-docs/) |
| Página de presentación del proyecto | `apps/landing/` (ignorada por git por ahora; solo contiene un handoff de marca local) |

El código del robot no está bajo `other/`: vive en [`../src/`](../src/), porque
es material de competencia. Los contratos compartidos, en cambio, se movieron
aquí a [`contracts/`](contracts/) junto con sus consumidores (`apps/`), para que
la raíz quede solo con lo que pide la WRO más `src/`.

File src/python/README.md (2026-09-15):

# src/python

Python/ROS2 code that runs on the robot itself: hardware drivers, navigation, the
competition state machine, vision, and a headless simulation harness for testing navigation
logic without hardware or Gazebo.

## Three source trees, one relationship

- **`src/`** (this directory's own `src/`, i.e. `src/python/src/`) - the actual
  implementation. Plain Python, importable and testable without ROS2 running
  (`tests/unit/` exercises this directly).
- **`ros2_ws/src/`** - ROS2 ament packages (`vtitan_bringup`, `vtitan_drivers`,
  `vtitan_navigation`, `vtitan_state_machine`, `vtitan_vision`). Node entry points here are
  thin wrappers: they import from `src/` and adapt it to ROS2 topics/params/lifecycle. This
  keeps the actual logic testable outside ROS2 and avoids duplicating it between a "plain"
  and a "ROS2" copy.
- **`shared/`** - a separate installable Python package (`shared.config`, `shared.domain`,
  `shared.io`), shared across this stack's own ROS2 nodes and simulation harness. Holds the
  pydantic-settings models and loaders that read the TOML under `src/config/` (repo root,
  outside `src/python/` entirely -- Go reads the same TOML tree), not the TOML itself.

Build the ROS2 workspace with `task robot:build-ws` (Linux only - colcon) before any
`run-`/`launch-` task.

## `src/` layout

| Directory | Contents |
|---|---|
| `hardware/` | Per-sensor/actuator drivers (camera, LIDAR passthrough, IMU variants, motors, button, display, Hailo NPU). Each has a `Config` (pydantic-settings, reads `src/config/hardware/*.toml` at the repo root) and a `Driver`. |
| `navigation/` | `CoreNavigator` and its controllers (pure pursuit, collision avoidance, stuck detection), maneuvers (parking, K-turn/slalom escapes), and planning (waypoint generation, sign routing/discovery, corridor estimation). Tunable via `NavigationTuning` (the `shared` package's `shared.config.navigation_tuning`), not hardcoded - the TOML itself lives at `src/config/navigation/*.toml` (repo root). |
| `state_machine/` | The 4-stage competition state machine (BOOT_CHECK → READY → RACING → FINISHED) and its data types. |
| `simulation/` | Headless closed-loop simulator: drives the real `CoreNavigator` against a simulated `HardwareGateway` (Ackermann kinematics + raycast LIDAR + collision), used for navigation regression testing without Gazebo. |
| `vision/` | Traffic-sign detector (Hailo NPU on hardware, Ultralytics/YOLO fallback in sim). |
| `ros2/` | The plain-Python side of ROS2 node logic that `ros2_ws/`'s node wrappers call into (parameter handling, topic callback logic) - kept here rather than in `ros2_ws/` for the same testability reason as everything else in `src/`. |
| `teleop/` | Bench-testing joystick teleop tool. |
| `config/`, `gen/`, `logger/` | Env/config loading (this package's own, distinct from the repo-root `src/config/` TOML tree), generated code, structured JSON logging setup. |

Hardware config lives under `src/config/hardware/*.toml` at the repo root (one file per
driver, read via pydantic-settings - see each driver's `Config`), alongside
`src/config/navigation/*.toml` (navigation tuning) and `src/config/robot.toml` (cross-language
physical constants). The `shared` package's `shared.config` is the Python loader for this
tree, not a copy of it -- Go reads the same TOML files directly.

## Testing

- `tests/unit/` - plain-Python tests against `src/` directly, no ROS2 required. Includes the
  closed-loop simulation regression suite (`test_obstacles_challenge_sim.py`,
  `test_deviation_recovery.py`, etc.).
- `tests/ros2/` - tests that exercise the ROS2 node wrappers.
- `tests/hardware/` - tests against real hardware drivers; most require the actual sensor
  attached and are skipped otherwise.

Run via `task robot:test` (`SCOPE=all|unit|hardware`, default `all` excludes on-device
hardware tests).

## Key Taskfile entry points

See `task --list` (or the repo root `Taskfile.yml`'s `ROBOT`/`ROBOT REMOTE` sections, defined in
`tasks/platform.yml`) for
the full list - `robot:install`, `robot:test`, `robot:lint`, `robot:run` (single node),
`robot:launch` (node sets: `rpi5`/`rpi-zero`/`state-machine`/`telemetry`/`simulator`/`lidar`),
`robot:deploy` (ship code to the Pi 5 over SSH), and `robot:drive`/`robot:reset-motors` for
runtime control-mode switching.

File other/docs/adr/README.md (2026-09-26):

# Architecture Decision Records

One Markdown file per decision. These hold the *why*: the measurements, the
run ids, the options considered, and the premises that were later refuted.
The config values live in `src/config/`, their short descriptions live in the
JSON Schemas (`src/model/`), and each schema key points here through
`x-journal`.

## Why separate files

A single growing engineering log does not scale for per-value justification:
the log is a curated, regulation-shaped deliverable, and it would balloon.
Small per-decision files stay reviewable, blame-able, and conflict-free.

## Reference from a schema

```json
"collision_thickness": {
  "x-journal": "adr:0001-wall-collision-thickness"
}
```

- `adr:<stem>` resolves to `other/docs/adr/<stem>.md`.
- A plain string is a repo-root-relative path, optionally with `#anchor`.
- A list is allowed when genuinely independent decisions touched one value.
- One evolving story should be a supersede chain (see below), not a list.

`task config:check` fails if any reference does not resolve.

## Chain, do not pile up

When a later decision replaces an earlier one, the new ADR supersedes the old
and carries `Supersedes: 0001` in its header, while the old ADR's status becomes
`superseded by NNNN`. The schema keeps only the current ADR; the history is the
chain. When one variable was touched many times, the current ADR tells the whole
story in its `## History` section rather than spawning a micro-ADR per attempt.

## Naming and status

`NNNN-slug.md`, zero-padded, assigned in order. Status is `proposed`,
`accepted`, `superseded by NNNN`, or `deprecated`.

## Index

| ADR | Title | Status |
|---|---|---|
| [0001](0001-wall-collision-thickness.md) | Wall collision thickness matches the visual wall | superseded by 0062 |
| [0002](0002-lidar-mount-forward-shift.md) | LIDAR collision geometry sits at the real mount | superseded by 0080 |
| [0003](0003-track-constants-single-source.md) | Track constants live in one source | superseded by 0069 |
| [0004](0004-corridor-division-lines-single-definition.md) | Corridor division lines are defined once | superseded by 0069 |
| [0005](0005-pillar-displacement-tolerance.md) | Pillars are displaced, not scored as first contact | superseded by 0062 |
| [0006](0006-parking-bay-scales-by-robot-length.md) | Parking bay length scales by the robot's length | superseded by 0062 |
| [0007](0007-starting-zone-spawn-alignment.md) | Spawn hugs one band edge, never centred | accepted |
| [0008](0008-robot-constants-single-source.md) | Robot constants live in one source and are read at runtime | superseded by 0069 |
| [0009](0009-chassis-mass-battery-middle-value.md) | Chassis mass is the middle of the battery configurations | superseded by 0077 |
| [0010](0010-wheel-angle-derived-from-steering.md) | Road-wheel angle is derived from the steering hardware | superseded by 0076 |
| [0011](0011-hardware-profile-fields-required.md) | Swappable servo and motor limits live in the hardware profile | superseded by 0070 |
| [0012](0012-yaw-gain-measured.md) | Yaw gain is a measured fraction of the kinematic model | superseded by 0086 |
| [0013](0013-turn-radius-speed-curve.md) | The turn-radius floor is speed-dependent | superseded by 0086 |
| [0014](0014-lidar-scan-plane-recessed.md) | The LIDAR scan plane is recessed, 0.08 m off the floor | superseded by 0080 |
| [0015](0015-lidar-inverted-mount.md) | The LIDAR is mounted upside-down | superseded by 0080 |
| [0016](0016-sensor-specs-consolidated.md) | Sensor specs are consolidated into robot.toml | superseded by 0069 |
| [0017](0017-ros-topics-centralized.md) | ROS2 topic names are centralized | superseded by 0069 |
| [0018](0018-competition-specs-single-source.md) | Competition round rules live in config, not Python literals | superseded by 0069 |
| [0019](0019-simulation-robot-model-topic-split.md) | Wheel geometry is split off the simulated track topic | accepted |
| [0020](0020-config-loaded-at-runtime.md) | Config is read at runtime from TOML, not generated into consumers | superseded by 0069 |
| [0021](0021-hardware-profiles-stackable-overlays.md) | Hardware profiles are stackable partial overlays | superseded by 0070 |
| [0022](0022-steering-physics-vs-policy.md) | Steering physics and steering policy are separate fields | superseded by 0050 |
| [0023](0023-escape-durations-in-seconds.md) | Escape durations are stored in seconds, not frames | superseded by 0055 |
| [0024](0024-localization-jump-guard-tracks-drivetrain.md) | The localization jump guard tracks the drivetrain ceiling | superseded by 0084 |
| [0025](0025-global-relocalization.md) | A lost pose is recovered by global relocalization | superseded by 0084 |
| [0026](0026-corridor-follower-no-centering.md) | The corridor follower does not centre | superseded by 0057 |
| [0027](0027-corner-steer-cap-commit-distance.md) | The corner-turn steering cap scales with commit distance | superseded by 0049 |
| [0028](0028-waypoint-center-bias-split.md) | Waypoint centre bias is split by corridor class | superseded by 0057 |
| [0029](0029-open-challenge-lookahead.md) | The Open Challenge uses its own lookahead | superseded by 0052 |
| [0030](0030-servo-slew-rate-split.md) | The servo slew rate is split from the steering-rate policy | superseded by 0076 |
| [0031](0031-clearance-thresholds-distance-not-time.md) | Clearance thresholds are distance, not time | superseded by 0085 |
| [0032](0032-heading-single-crawl-threshold.md) | Heading correction is a single crawl threshold | superseded by 0085 |
| [0033](0033-per-challenge-speed-ladders.md) | The per-challenge speed ladders are a deliberate split | superseded by 0085 |
| [0034](0034-wrong-side-pass-ground-truth.md) | Wrong-side passes are scored from ground truth | superseded by 0059 |
| [0035](0035-obstacles-pass-side-tracking.md) | The Obstacles pass-side deficit is tracking, not routing | superseded by 0059 |
| [0036](0036-no-parking-after-final-lap.md) | Parking is not pursued after the final lap | superseded by 0062 |
| [0037](0037-parking-lot-from-in-bay-start.md) | The parking lot is derived from the in-bay start | superseded by 0062 |
| [0038](0038-bay-exit-mirror-reverse-steer.md) | The bay exit mirrors its reverse-leg steering | superseded by 0060 |
| [0039](0039-obstacles-contact-zone.md) | The Obstacles contact zone is per-challenge | superseded by 0061 |
| [0040](0040-rear-self-detection-chassis-geometry.md) | The rear self-detection filter follows chassis geometry | superseded by 0056 |
| [0041](0041-lidar-valid-range-floor.md) | The LIDAR valid-range floor sits below the rated minimum | superseded by 0056 |
| [0042](0042-sign-range-fusion-gated.md) | Sign range fusion is gated and paired with cluster detection | superseded by 0058 |
| [0043](0043-obstacles-inner-wall-scoring.md) | Obstacles inner-wall contact scoring is configurable | superseded by 0059 |
| [0044](0044-camera-autofocus-dioptre.md) | The camera autofocus is set to 1.25 dioptres | superseded by 0078 |
| [0045](0045-sign-router-commit-hysteresis.md) | The sign router holds its committed sign | superseded by 0051 |
| [0046](0046-repo-layout-src-apps.md) | The repository layout moves code into src/ and apps/ | accepted |
| [0047](0047-contact-reverse-ships-disabled.md) | The contact reverse ships disabled | superseded by 0088 |
| [0048](0048-risk-ray-window-noise-statistics.md) | The forward lane corroborates a short return across adjacent rays | superseded by 0056 |
| [0049](0049-corner-arcs-per-corridor-and-commit-distance.md) | Corner arcs are sized per corridor and the steering cap from the commit distance | accepted |
| [0050](0050-escape-steering-degrees-and-committed-side.md) | Escape steering is physical road-wheel degrees and follows the committed pass side | accepted |
| [0051](0051-sign-lane-planner.md) | Sign avoidance rewrites the path into a lane | accepted |
| [0052](0052-pursuit-target-selection.md) | Pursuit selects its target by arc length and path sense, and arms the lookahead on the corner ahead | accepted |
| [0053](0053-direction-inference-and-start-pose.md) | Direction is inferred from the corridor span and the start pose from the scan | accepted |
| [0054](0054-absolute-heading-from-walls.md) | Absolute heading is read off the Manhattan walls, mod 90 | accepted |
| [0055](0055-escape-maneuver-selection.md) | The escape manoeuvre fails closed on an unread rear, pivots when wedged, and re-anchors at its end | accepted |
| [0056](0056-raw-and-masked-scan.md) | The scan is read twice, raw for speed and masked for the escape | accepted |
| [0057](0057-blind-corridor-follower-and-width.md) | The blind corridor follower does not centre, and width is classified not measured | accepted |
| [0058](0058-sign-discovery-range-and-barrier-belief.md) | Sign discovery takes the closest observation and bounds ingest by range | accepted |
| [0059](0059-pass-side-travel-relative-and-scorer-independence.md) | The pass-side rule is travel-relative, and a scorer must not share the scored system's convention | accepted |
| [0060](0060-bay-exit-clearance-guard.md) | The bay exit is bounded by predicted fin clearance, not by contact | accepted |
| [0061](0061-contact-zone-per-challenge.md) | The contact zone is per challenge | accepted |
| [0062](0062-sim-contact-model-and-parking.md) | The simulator scores the rulebook contact model, and parking is a RACING phase | accepted |
| [0063](0063-corridor-flip-and-sense-guards.md) | The corridor flip and the sense guards are temporal, not geometric | accepted |
| [0064](0064-corridor-by-depth-and-clearance-budget.md) | A corner sign's corridor is decided by depth, and the clearance budget is thin | accepted |
| [0065](0065-fastdds-udp-only.md) | FastDDS shared memory is disabled and transport is UDP only | accepted |
| [0066](0066-two-board-compute-split.md) | Compute is split Pi 5 perception and Pi Zero real-time control | accepted |
| [0067](0067-usb-gadget-link-and-provisioning.md) | The board link is an NM-only USB-gadget subnet and the Zero receives built tarballs | accepted |
| [0068](0068-go-parallel-track-single-cutover.md) | The Go stack is a parallel track with a single cutover | accepted |
| [0069](0069-config-governance.md) | Config values live in TOML, descriptions in schemas, rationale in ADRs | accepted |
| [0070](0070-hardware-profiles-and-challenge-overlays.md) | Hardware profiles are per-component overlays and a wrong name fails loud | accepted |
| [0071](0071-round-recording-mcap.md) | Every round is recorded as an MCAP bag and analyzed offline | accepted |
| [0072](0072-vision-data-path.md) | The camera feeds the NPU in-process and vision owns identity, not distance | accepted |
| [0073](0073-challenge-mode-jumper-and-runtime.md) | The challenge is read from a boot jumper and resolved at runtime | accepted |
| [0074](0074-control-loop-rate-single-source.md) | The control loop rate has a single source | accepted |
| [0075](0075-counter-phase-four-wheel-steering.md) | Four-wheel counter-phase steering replaces Ackermann | deprecated (merged into 0076) |
| [0076](0076-drivetrain-and-steering-hardware.md) | The drivetrain is sized on measured current, and calibration is never inherited | accepted |
| [0077](0077-power-rails-and-chassis-mass.md) | Power rails are sized to measured load and the chassis mass is the battery midpoint | accepted |
| [0078](0078-camera-mount-and-focus.md) | The camera is mounted above the LIDAR and its lens is parked on the decision range | accepted |
| [0079](0079-imu-6axis-and-yaw-reference.md) | The IMU runs 6-axis and its reference is zeroed at the start button | accepted |
| [0080](0080-lidar-mount-and-scan-plane.md) | The LIDAR is modelled at its real mount, inverted, with a recessed scan plane | accepted |
| [0081](0081-step-stl-parts-and-naming.md) | Every 3D part is published as STEP and STL with kebab-case names | accepted |
| [0082](0082-wiring-harness-as-code.md) | The wiring harness is defined as code | accepted |
| [0083](0083-oled-backend-and-button-thresholds.md) | The OLED has a raw-I2C fallback and the button thresholds escalate | accepted |
| [0084](0084-localizer-divergence-and-relocalization.md) | Pose divergence is detected off-track and recovered by armed global relocalization | accepted |
| [0085](0085-speed-envelope.md) | The speed envelope is absolute m/s with the drivetrain as a clamp | accepted |
| [0086](0086-simulator-realism.md) | The simulator runs on a measured error budget, not a perfect world | accepted |
| [0087](0087-test-methodology.md) | Testing uses a four-level ladder and a fixed A/B protocol | accepted |
| [0088](0088-refuted-config-knobs.md) | Refuted config knobs ship off and stay documented | accepted |
| [0089](0089-robot-constants-runtime-and-xacro.md) | Robot constants are read at runtime and the xacro is the one hand-synced copy | deprecated (merged into 0069) |
| [0090](0090-commit-and-constant-conventions.md) | Commit messages and constant access follow fixed conventions | accepted |
| [0091](0091-dataset-frame-capture.md) | Dataset frames are captured periodically beside the run artifacts | accepted |
| [0092](0092-escape-does-not-retire-committed-sign.md) | An escape does not retire the committed sign, and ships off | accepted |
| [0093](0093-marker-serialization-and-cube-markers.md) | Marker geometry is float-typed at the model boundary and solid markers use CUBE | accepted |
| [0094](0094-pkg-is-the-public-surface.md) | `pkg/` is the Go module's public surface and may not import `internal/` | accepted |
| [0095](0095-pi5-board-composition-root.md) | `cmd/pi5` composes the Pi 5 board, and each subsystem's loop is shared | accepted |
| [0096](0096-vt-cli-wraps-the-taskfiles.md) | `vt` wraps the Taskfiles, and migrates to Go only what has real logic | accepted |
| [0097](0097-doc-ownership-and-drift-checks.md) | Tracked prose owns only the present it can be checked against, and a docs check enforces it | accepted |
| [0098](0098-pico-actuation-board-and-portable-cores.md) | A Pico 2 is an alternative actuation board, and the logic both boards share lives in `pkg/portable` | accepted |
| [0099](0099-blind-round-frame-contract.md) | A blind round runs in one believed frame, built by one component on the robot and in the sim | proposed |

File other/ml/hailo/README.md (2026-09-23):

# Hailo Pipeline

Host-side CLI toolchain for compiling YOLO models to Hailo 8 HEF format.

## Quick Start

```bash
# Install dependencies
uv sync

# Export a YOLO model to ONNX
uv run hailo export --model yolo11s

# Prepare calibration data
uv run hailo calib download
uv run hailo calib convert

# Stage files for Docker and run the compiler
uv run hailo stage --model yolo11s
uv run hailo compile --model yolo11s --docker hailo8_ai_sw_suite_2025-10_container
```

Or use the Taskfile for the full pipeline:

```bash
task hailo:env:setup         # uv sync
task hailo:model:export      # yolo11s → ONNX
task hailo:calib:prepare     # download + convert
task hailo:workflow:full     # export → calib → test → stage → start Docker
```

## Project Structure

```
hailo/
├── main.py               # CLI entry point (argparse dispatch)
├── src/
│   ├── config.py         # Frozen dataclasses per command (no logic)
│   ├── docker.py         # Container lifecycle + docker exec
│   ├── export.py         # YOLO .pt → ONNX via Ultralytics
│   ├── hailomz.py        # stage / compile / eval / profile
│   ├── calib.py          # COCO download (fiftyone) + image → .npy
│   ├── graph.py          # ONNX graph inspection
│   ├── test.py           # 3-backend inference runner (pt/onnx/ultraonnx)
│   ├── image.py          # Letterbox, preprocessing, annotation drawing
│   ├── coco.py           # COCO 2017 class labels + per-class colours
│   ├── registry.py       # Model registry (known YOLO variants)
│   ├── enums.py          # Backend, Task, HWArch, EvalTarget
│   ├── errors.py         # HailoError hierarchy + require_dep guard
│   └── log.py            # Structured JSON logging
├── eval/                 # Accuracy comparison between compiled builds
│   ├── metrics.py        # mAP, per-class AP, class confusion (no SDK deps)
│   ├── compare_hars.py   # Scores quantized HARs - runs inside the container
│   └── float_anchor.py   # Scores the float checkpoint - runs on the host
├── pyproject.toml
├── Taskfile.yml          # Task runner workflows
├── shared_with_docker/   # Mounted into the Hailo suite container
├── data/                 # Model checkpoints and ONNX exports
├── calib_data/           # Raw calibration images
├── calib_data_npy/       # float32 .npy arrays for hailomz
└── test_output/          # Annotated inference results
```

## Environment

The host-side commands (`export`, `calib`, `inspect`, `test`, `stage`) run on
any platform, including Windows.

The Hailo AI Software Suite ships as a Linux container image, so `docker run`,
`compile`, `eval`, and `profile` all go through Docker:

- **Compile and emulator-based eval** (`--target emulator`) need no Hailo
  hardware. They run on **WSL2**, and on **Docker Desktop** via
  `hailo docker run --compile-only`.
- **Hardware eval/profile** (`--target hailo8`) need a native Linux host with
  the Hailo-8 device attached (PCIe passthrough is not available under WSL2).

`task hailo:docker:run` reproduces the vendor script's full mount set, which only
exists on a Linux host. On Docker Desktop use `task hailo:docker:run-compile-only`,
which starts a minimal detached container carrying just the shared mount.

The suite image itself is a manual download from the Hailo Developer Zone -
`docker pull` will not find it. Load it once with `task hailo:docker:load`.

> Compiling on Windows has several non-obvious failure modes, including one that
> silently produces a *less accurate* HEF rather than an error. See
> [docs/hef-compile-runbook.md](docs/hef-compile-runbook.md).

The suite image and container are overridable per build: pass `--image`/
`--container` to `hailo docker run`, or override `DOCKER_IMAGE`/`DOCKER_CONTAINER`
when calling a `task` command.

## Commands

| Command | Description |
|---|---|
| `export` | Export a YOLO `.pt` checkpoint to ONNX |
| `calib download` | Download COCO 2017 validation images for calibration |
| `calib convert` | Convert calibration images to float32 `.npy` arrays |
| `inspect` | Print ONNX graph structure, inputs, outputs |
| `test` | Run inference locally (`--backend pt`/`onnx`/`ultraonnx`) |
| `stage` | Copy ONNX and calibration data into `shared_with_docker/` |
| `compile` | Run `hailomz compile` inside the suite container |
| `eval` | Run `hailomz eval` (emulator or Hailo-8 hardware) |
| `profile` | Run `hailomz profile` (HEF performance measurement) |
| `docker run` | Start the Hailo AI Software Suite container |

## Taskfile Reference

The pipeline includes a [`Taskfile.yml`](Taskfile.yml) with workflows for every stage. Install
[Task](https://taskfile.dev/) and run:

```bash
task --list
```

All tasks follow the `namespace:verb` convention. Variables are overridable on
the command line:

```bash
task hailo:model:export MODEL=yolo12n
task hailo:eval:run TARGET=hailo8 DATA_COUNT=100
```

### Variables

| Variable | Default | Description |
|---|---|---|
| `MODEL` | `yolo11s` | Model registry key |
| `IMGSZ` | `640` | Input resolution |
| `SAMPLES` | `2048` | Calibration dataset size |
| `CALIB_INPUT` | `./calib_data` | Raw calibration images directory |
| `CALIB_OUTPUT` | `./calib_data_npy` | float32 .npy output directory |
| `TEST_INPUT` | `./calib_data` | Test images directory |
| `TEST_OUTPUT` | `./test_output` | Annotated output directory |
| `TEST_CONF` | `0.3` | Confidence threshold |
| `SHARED_DIR` | `./shared_with_docker` | Docker shared volume mount |
| `DOCKER_CONTAINER` | `hailo8_ai_sw_suite_2025-10_container` | Container name |
| `DOCKER_IMAGE` | `hailo8_ai_sw_suite_2025-10:1` | Suite image tag |
| `HW_ARCH` | `hailo8` | Target hardware |
| `TARGET` | `emulator` | Evaluation target |
| `DATA_COUNT` | `512` | Evaluation samples |
| `GMR_CALIB_SRC` | `../apps/auto-annotator/ml-service/data/images` | Prism calibration images for `gmr` |
| `GMR_CALIB_NAME` | `calib_data_gmr` | Staged calibration subdirectory for `gmr` |

### Environment

| Task | Description |
|---|---|
| `task hailo:env:setup` | Install dependencies (`uv sync`) |
| `task hailo:env:list` | Show installed packages |

### Model Export

| Task | Description |
|---|---|
| `task hailo:model:export` | Export `MODEL` to ONNX |
| `task hailo:model:export-all` | Export all registered models (n/s/m) |
| `task hailo:model:inspect` | Print ONNX graph of `MODEL` |
| `task hailo:model:export-inspect` | Export then inspect |

### Calibration Data

| Task | Description |
|---|---|
| `task hailo:calib:download` | Download COCO 2017 validation images |
| `task hailo:calib:convert` | Convert images to float32 `.npy` |
| `task hailo:calib:prepare` | Download + convert (full pipeline) |

### Testing / Inference

| Task | Description |
|---|---|
| `task hailo:test:onnx` | Test with raw ONNX backend |
| `task hailo:test:ultraonnx` | Test with Ultralytics ONNX backend |
| `task hailo:test:run BACKEND=<backend>` | Run with explicit backend |

### Staging for Docker

| Task | Description |
|---|---|
| `task hailo:stage:run` | Stage ONNX + calibration data into `shared_with_docker/` |
| `task hailo:stage:no-calib` | Stage ONNX only (no calibration data) |

### Docker Container Management

| Task | Description |
|---|---|
| `task hailo:docker:load` | Load the suite image from its Developer Zone tarball |
| `task hailo:docker:run` | Start the container with the full Linux mount set |
| `task hailo:docker:run-compile-only` | Start a minimal detached container (Docker Desktop / Windows) |
| `task hailo:docker:dry` | Print the docker run command without executing |
| `task hailo:docker:status` | Check if the container is running |
| `task hailo:docker:stop` | Stop the container |
| `task hailo:docker:logs` | Follow container logs |

### Compile, Evaluate, Profile

| Task | Description |
|---|---|
| `task hailo:compile:run` | Compile ONNX → HEF (requires running container) |
| `task hailo:compile:dry` | Print compile command only |
| `task hailo:eval:run` | Evaluate HEF on target |
| `task hailo:eval:dry` | Print eval command only |
| `task hailo:eval:visual` | Evaluate with visualization |
| `task hailo:profile:run` | Profile HEF performance |
| `task hailo:profile:dry` | Print profile command only |

### GMR (retrained 3-class model)

| Task | Description |
|---|---|
| `task hailo:gmr:export` | Export the retrained checkpoint to ONNX |
| `task hailo:gmr:stage` | Stage ONNX + prism calibration images |
| `task hailo:gmr:compile` | Compile to HEF (requires running container) |
| `task hailo:gmr:compile-performance` | Compile at the highest optimization level (needs a GPU) |
| `task hailo:gmr:compile-dry` | Print the compile command only |
| `task hailo:gmr:workflow` | export → stage → compile |

### Accuracy Evaluation

Distinct from `eval:*` above, which wraps `hailomz eval` against a target.
These score detections and compare compiled builds against the float ceiling -
the optimization level that produces the most accurate HEF is an empirical
question per model, not a given. See
[docs/hef-compile-runbook.md](docs/hef-compile-runbook.md).

| Task | Description |
|---|---|
| `task hailo:gmr:stage-eval` | Stage GMR images **and labels** for the evaluators |
| `task hailo:accuracy:float` | Score the float checkpoint (host) - the ceiling |
| `task hailo:accuracy:compare` | Score every compiled HAR (in the container) |
| `task hailo:accuracy:all` | Float ceiling, then every HAR |

Override the sample size with `task hailo:accuracy:all EVAL_LIMIT=600`.

### End-to-End Workflows

| Task | Description |
|---|---|
| `task hailo:workflow:full` | export → calib → test → stage → start Docker |
| `task hailo:workflow:compile` | stage → compile in Docker |
| `task hailo:workflow:eval` | compile → eval → profile |

### Maintenance

| Task | Description |
|---|---|
| `task hailo:clean:output` | Remove test outputs and exported models |
| `task hailo:clean:calib` | Remove calibration data |
| `task hailo:clean:all` | Remove all generated files |
| `task hailo:log:run LEVEL=DEBUG\|INFO\|WARNING ARGS=<cmd>` | Run a command with a specific log level |

## Model Registry

The [`src/registry.py`](src/registry.py) module registers known YOLO variants with
their export metadata and Hailo Model Zoo identifiers:

| Key | Task | Opset | Zoo Name | Notes |
|---|---|---|---|---|
| `yolo11n` | detect | 13 | `yolov11n` | Ultralytics defaults |
| `yolo11s` | detect | 13 | `yolov11s` | Ultralytics defaults |
| `yolo12n` | detect | 11 | `yolov12n` | `nms=False`, `simplify=True` |
| `yolo26n` | detect | 11 | - | No zoo entry |
| `yolo26l` | detect | 11 | - | No zoo entry |
| `yolo26l-seg` | segment | 11 | - | Segmentation variant |
| `gmr` | detect | 13 | `yolov11n` | Retrained, 3 classes |

Models without a zoo name require `--zoo-name` when calling `compile`/`eval`/`profile`.

### Retrained models

`gmr` is the apps/auto-annotator's retrained YOLO11n - green / red / magenta
rectangular prism - living at
`../apps/auto-annotator/ml-service/models/gmr/best.pt`. It shares the stock
`yolo11n` architecture, so it compiles against the zoo's `yolov11n` graph
config; only the class count differs. The registry entry carries
`classes=3`, which `compile` forwards as `hailomz --classes 3` so the NMS
config is regenerated for the real class count instead of COCO's 80.

Two things differ from the stock workflow:

- **Calibration data is domain-specific.** `task hailo:gmr:stage` calibrates on the
  apps/auto-annotator's own prism photographs, not COCO. Quantisation ranges
  derived from out-of-domain images cost real accuracy on a colour-critical
  detector. The images are nested per class, so `stage` walks the source
  directory recursively and flattens it - `hailomz` reads calibration images
  from a single flat directory.
- **The staged calibration set is namespaced.** `--calib-name calib_data_gmr`
  keeps it from overwriting the COCO set used by the stock models. Pass the
  matching `--calib-path` to `compile`.

```bash
task hailo:gmr:workflow          # export → stage → compile
task hailo:gmr:compile-dry       # print the hailomz command without a container
```

For any other retrained checkpoint, add a registry entry with its `.pt` path,
the zoo name of its base architecture, and its `classes` count.

## Docker Workflow

The Hailo AI Software Suite runs inside a Linux Docker container. The pipeline
manages the full lifecycle:

1. **Start the container** - `task hailo:docker:run` mounts `shared_with_docker/` at
   `/local/shared_with_docker/` inside the container, forwards X11 for GUI
   tools, and exposes GPU devices.
2. **Stage files** - `task hailo:stage:run` copies the ONNX model and calibration
   data into `shared_with_docker/`.
3. **Compile** - `task hailo:compile:run` executes `hailomz compile` via `docker exec`,
   producing a `.har` (Hailo Archive) and `.hef` (Hailo Executable Format) file.
4. **Evaluate** - `task hailo:eval:run` runs `hailomz eval` on the emulator or
   connected Hailo-8 hardware.
5. **Profile** - `task hailo:profile:run` measures inference performance.

All docker commands accept `--docker CONTAINER` to target a specific container,
or omit it to print the equivalent shell command for manual execution.

## Development

```bash
# Setup
uv sync

# List all taskfile workflows
task list

# Lint
uv run --group dev ruff check src/

# Run the full pipeline
task hailo:workflow:full
```

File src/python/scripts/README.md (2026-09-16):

# Robot scripts

Grouped by **what you need in order to run it**, which is the axis that actually
decides where a script can execute and what it can tell you.

| folder | needs | what lives here |
|---|---|---|
| `bag/` | a recorded `.mcap` run | replay diagnostics - drive the real navigation classes over a bag and report what they did |
| `sim/` | nothing | closed-loop simulation sweeps and scenario harnesses |
| `hardware/` | the real robot | live probes and motor/vision utilities that talk to ROS2 topics or peripherals |
| `vision/` | the `vision` pixi env | HUD preview and camera-logo tooling |
| `provisioning/` | SSH to a Pi | bootstrap, deploy, shutdown and recovery shell ops |
| `sync/` | SSH to a Pi | pull/push recorded runs and videos to/from a Pi |
| `common/` | - | shared helpers imported by the above, not run directly |
| `*.sh` | SSH to a Pi | bench-mode HUD recording, vision recording, joystick pairing |

The shell ops scripts in `provisioning/`, `sync/` and the top level stay where
they are because `pixi.toml` tasks, the platform `Taskfile.yml` and the docs
all pin their paths.

## Map of the diagnostics

There are ~150 `diag_*.py` scripts, and `bag/` alone holds ~100 of them. They
are **not** split into subfolders: the filename is the namespace, and every
script is one self-contained question about one domain. The glob below is the
index -- list a row's glob to see the scripts in that domain. Read the module
docstring at the top of each: it is the question, the method, and the result,
not a summary of the code.

### `bag/` - replays of a recorded run

| domain | scripts | what the domain answers |
|---|---|---|
| pass side / routing | `diag_bag_pass_*.py`, `diag_bag_pair_crossing*.py`, `diag_bag_cross_attempt.py`, `diag_bag_exec_failures.py`, `diag_bag_side_correction_outcome.py`, `diag_bag_reverse_budget.py`, `diag_bag_lane_reconstruct.py` | did the router command the legal side, and did the chassis get there; separate routing from execution |
| signs | `diag_bag_sign_*.py`, `diag_bag_green_loss.py`, `diag_bag_colour_split.py` | discovery, colour voting, track birth, believed-layout reconstruction |
| commitment | `diag_bag_commit_*.py` | when and why the router committed to a sign |
| escape / stuck | `diag_bag_escape*.py`, `diag_bag_dwell_loop.py`, `diag_bag_creep_stall.py`, `diag_bag_blend_reachability.py` | the reactive layer: when it fires, which side, and what it buys. `diag_bag_escape_counter.py` prices the escalation ladder, which never reaches its third attempt |
| bay / parking | `diag_bag_bay_*.py`, `diag_bag_barrier_gate.py`, `diag_bay_slip.py`, `diag_bag_parking_attempts.py` | the pocket and parking manoeuvres |
| contact / clearance | `diag_bag_contact_*.py`, `diag_bag_proximity.py`, `diag_bag_side_ray_robustness.py`, `diag_bag_subfloor_ranges.py`, `diag_bag_wedge_trace.py`, `diag_bag_scan_occupancy.py` | how close contact came, and LIDAR dropouts under it |
| localizer / LIDAR | `diag_localizer_*.py`, `diag_bag_localizer_divergence.py`, `diag_bag_lidar_proposer.py`, `diag_bag_mask_*.py`, `diag_bag_rear_sector_measured.py`, `diag_bag_lidar_frame_census.py`, `diag_bag_yaw_frame_offset.py`, `diag_yaw_flip_replay.py` | pose and scan matching against the believed track; the census prints BOTH frames, because the mount offset was read wrong once |
| lap / race | `diag_bag_lap_*.py` | lap counting, the start/finish line, and what each lap cost (`diag_bag_lap_timeline.py`) |
| direction | `diag_bag_direction_*.py` | direction inference gates and votes |
| steering / motion | `diag_bag_steer*.py`, `diag_bag_steering_response.py`, `diag_bag_drive_response.py`, `diag_bag_servo_echo.py`, `diag_bag_turn_*.py`, `diag_bag_corner_*.py`, `diag_bag_angle_error.py` | actuator response and cornering |
| vision | `diag_bag_vision.py`, `diag_bag_camera_smear.py`, `diag_bag_detection_reach.py`, `diag_vision_range_ceiling.py` | detection quality on recorded frames |
| corpus / sessions | `diag_bag_session_*.py`, `diag_bag_fleet_compare.py`, `diag_bag_summary.py`, `diag_bag_review.py`, `diag_bag_sim_fidelity.py`, `diag_bag_topic_gaps.py` | inventory, cross-run reports, and whether a topic went silent |
| sim fidelity | `diag_bag_fidelity_axes.py` | the HARDWARE half of the divergence audit -- pair it with `sim/diag_fidelity_axes.py` |

Anything not matched above is a one-off trace (`diag_bag_state_timeline.py`,
`diag_bag_imu_trace.py`, `diag_bag_path_replay.py`, ...); it still follows the
same one-script-one-question rule.

### `sim/` - closed-loop sweeps, need no hardware or bag

| domain | scripts | what the domain answers |
|---|---|---|
| Open Challenge population | `diag_open_*.py` | direction, laps, narrow corridors, corner geometry over the 640-case space |
| sign routing | `diag_sign_*.py` | lane building, pass side, hits, pairs, and router-flag A/Bs |
| A/B tuning harnesses | `diag_today_stack_ab.py`, `diag_vision_range_ab.py`, `diag_sign_slot_ab.py` | the same sample under two tunings, with the control printed; the slot-map A/B compares failing SETS, not counts |
| bay / parking | `diag_bay_*.py`, `diag_park_*.py`, `diag_pair_cells.py` | pocket entry/exit and parking feasibility |
| escape / blend | `diag_escape_*.py`, `diag_flush_*.py` | escape duration and side-correction blends |
| localizer / LIDAR | `diag_localization.py`, `diag_sim_lidar_proposer.py` | pose recovery and the LIDAR cluster proposer |
| path / width / clearance | `diag_path_track*.py`, `diag_width_probe.py`, `diag_wide_wall_hug.py`, `diag_collision_margin.py` | path geometry and margins |
| blind / failures | `diag_blind_layout.py`, `diag_failure_split.py`, `diag_obstacles_matrix.py` | blind-mode layout and failure attribution |
| sim fidelity | `diag_fidelity_axes.py` | the SIM half of the divergence audit -- pair it with `bag/diag_bag_fidelity_axes.py` |
| single runner | `run_scenario.py` | run one fixture, print its result as JSON, exit non-zero on a bad run |

### `hardware/` - talks to the real robot

`test_motors.py`, `calibrate_encoder.py`, `sweep_open_loop.py`,
`reset_motors.py`, `diag_servo_slew.py` (motors); `diag_hailo_detector.py`,
`diag_vision_topic.py`, `record_vision_video.py`, `watch_vision_detections.py`,
`diag_focus_sweep.py` (vision); `diag_scan_probe.py`, `diag_corridor_measure.py`
(sensors); `diag_track_run.py` (a whole flagged run). Only
`diag_hailo_detector.py` needs the `vision` pixi env.

### `common/` - imported, never run directly

| group | modules |
|---|---|
| bag replay | `bag_io.py`, `scenarios.py`, `pass_side.py`, `cross_attempt.py`, `episodes.py`, `sign_router_capture.py` |
| sim sweeps | `diag_base.py`, `sim_defaults.py`, `open_cases.py` |
| hardware/sim comparison | `fidelity_axes.py` -- the axis definitions the two `*fidelity_axes.py` probes must share |
| reporting | `tables.py`, `stats.py`, `formats.py`, `binning.py` |
| environment | `provenance.py`, `sensor_errors.py`, `hardware_defaults.py` |
| other | `lidar_clusters.py`, `motor_hold.py`, `analyze_rtps_pcap.py`, `check_imports.py` |

Import these as `from scripts.common.bag_io import ...`. A private helper that
two scripts share belongs here, not in one script imported by the other: a
private cross-script import is a hidden library, and the whole tree used to be
full of them.

## Running one

Every script is run from `src/python/` with the repo root on `PYTHONPATH`,
which the `dev` pixi env provides:

```
pixi run -e dev python scripts/bag/diag_bag_lap_replay.py ../../other/data/live/runs/run_20260806_180154
pixi run -e dev python scripts/sim/diag_open_laps.py
pixi run -e vision python scripts/hardware/diag_hailo_detector.py IMAGE...
```

`scripts/hardware/diag_hailo_detector.py` needs the `vision` env - `hailo_platform`
is only installed there and on the Pi 5.

## Adding one

Put it in the folder matching what it needs to run. Import shared helpers as
`from scripts.common.bag_io import ...`, and put the repo's robot root on the path
with `parents[2]`, not `parents[1]`:

```python
sys.path.insert(0, str(Path(__file__).resolve().parents[2]))

from scripts.common.bag_io import load_nav_debug_rows, print_table
```

## Checking the tree still imports

A folder move or a renamed helper breaks imports silently - nothing runs these
in CI. `scripts/common/check_imports.py` loads every script's top level (without
running `main()`) and reports what failed:

```
pixi run -e dev python scripts/common/check_imports.py
```

One expected failure off the Pi 5: `hardware/diag_hailo_detector.py`, for the
missing `hailo_platform` runtime.

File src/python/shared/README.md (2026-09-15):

# src/python/shared

Shared Python constants, enums, domain models, and utilities for the vTitan robot
stack. Installed as its own package (`shared`) so the ROS2 nodes, the simulation
harness and the diagnostic scripts all import one copy.

## Consumers

**`src/python` only.** Nothing else in this monorepo imports `shared`: the Go
backend (`other/apps/backend`), the Go robot stack (`src/go`) and the frontend
(`other/apps/frontend`) each keep their own type and constant definitions in
their own language rather than depending on this package.

The one thing that genuinely crosses languages is the TOML tree under
`src/config/` at the repo root. Python and Go both read those files directly at
runtime; there is no shared runtime object and no generated bridge between the
two stacks. See [ADR 0020](../../../other/docs/adr/0020-config-loaded-at-runtime.md).

## Where the configuration lives

The TOML is **not** in this package. It sits at the repo root, outside
`src/python/` entirely:

| Tree | Holds |
|---|---|
| `src/config/robot.toml` | Cross-language physical constants (chassis, Ackermann, wheel, LIDAR, camera mount) |
| `src/config/navigation/*.toml` | Navigation tuning, grouped by subsystem |
| `src/config/hardware/*.toml` | One file per driver |
| `src/config/profiles/*/` | Swappable hardware profiles, composed at `VTITAN_HARDWARE_PROFILE` |
| `src/model/*.schema.json` | The JSON Schemas that validate all of the above |

This package is the **Python loader** for that tree, not a copy of it.

## What's here

- `shared.config.robot_constants` - reads `src/config/robot.toml` at runtime
  (`DEFAULT_CONFIG_PATH`), applies the active hardware-profile overlays, and
  exposes the result as typed constants.
- `shared.config.constants` - `RobotSpecs`, `TrackDimensions`, `WallSpecs`,
  `TrafficSignSpecs`, `CompetitionSpecs`, `ParkingLotSpecs` and the identifier
  tables (`TfFrames`, `NodeNames`, `FolderNames`, ...). The chassis, Ackermann,
  LIDAR and camera-mount fields come from `robot_constants`; the simulation-only
  parameters are hand-maintained here, because nothing else duplicates them.
- `shared.config.navigation_tuning` - `NavigationTuning`, the runtime-tunable
  parameter set (pursuit, clearance, escape, sign routing, parking, ...), loaded
  from the per-group files under `src/config/navigation/`.
- `shared.config.generated` - DTOs generated from the JSON Schemas in
  `src/model/`. Do not hand-edit; they carry only the fields and their types.
- `shared.config.hardware_profile` - profile discovery and overlay composition.
- `shared.domain.enums` - `Section`, `Direction`, `Corridor`, `ScenarioType`,
  `RiskLevel`, `RobotState`, `NodeHealth`, `NavigatorPhase` and friends.
- `shared.domain.models` - `Pose`, `Velocity`, `Detection`, `LidarClearances`,
  `ScenarioMetadata` and the other cross-module data shapes.
- `shared.domain.steering`, `shared.config.coordinate_transform` - steering-angle
  conversion and frame transforms.
- `shared.io` - `JsonlReader` / `JsonlWriter` / `JsonlValidator` for
  session and replay files.

## A note on code generation

Two different things used to be called "codegen" here, and only one still exists:

- **Alive:** `shared.config.generated.*`, the DTOs built from the JSON Schemas in
  `src/model/`. Regenerate them rather than editing them.
- **Removed 2026-09-03:** the regenerator that pushed `robot.toml` into the Go
  and xacro consumers. Those are now **hand-maintained copies**, so a change to
  `robot.toml` has to be mirrored into them by hand. Python does not need it; it
  reads the TOML itself.

## Installing

`src/python`'s `pixi.toml` depends on this package by local path. There is no
separate install step; it is part of the robot's pixi environment.

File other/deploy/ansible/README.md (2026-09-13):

# Ansible provisioning

Idempotent, re-runnable Ansible roles, ported from the old `setup_pi_5.sh`/
`setup_pi_zero.sh` scp+ssh scripts (removed 2026-07-30). Runs from the
**dev Pi 5**, not from Windows - Ansible's control node needs a POSIX shell.

## Layout

- `inventory/hosts.yml` - `robot_pi5` / `robot_pi_zero` groups. `ansible_host`
  defaults mirror `Taskfile.yml`'s `RPI_LOCAL_IP`/`ZERO_WIFI_IP`; override with
  `-e ansible_host=<ip>` per run.
- `inventory/group_vars/all.yml` - shared vars (repo, paths, USB gadget subnet, WiFi
  band-lock BSSID). Mirrors the equivalent `Taskfile.yml` vars.
- `roles/common/` - GitHub auth, apt upgrade, hardware groups, pixi install,
  private repo clone, `.env`, udev rules. Shared by both boards.
- `roles/pi5/` - raspi-config interfaces, Hailo runtime (`apt install
  hailo-all`), `usb0` host static IP, `vision` pixi env, LiDAR driver,
  `vtitan-pi5`/`vtitan-lidar` systemd units.
- `roles/pi_zero/` - `config.txt`/`cmdline.txt` overlays, USB gadget MACs,
  `usb0` client static IP, swap bump, `dev` pixi env, `vtitan-pi-zero`
  systemd unit.
- `playbooks/provision_pi5.yml`, `playbooks/provision_pi_zero.yml`, `site.yml`
  (both, Pi 5 first).

## Usage

Prefer the `task rpi:provision:*` / `task rpi:ansible:*` wrappers in the root
`Taskfile.yml` - they set `GH_TOKEN` and pick the right playbook. Direct
invocation:

```bash
ansible-galaxy collection install -r requirements.yml   # one-time
GH_TOKEN=$(gh auth token) ansible-playbook playbooks/provision_pi5.yml -e pi5_ip=192.168.0.50 --ask-become-pass
GH_TOKEN=$(gh auth token) ansible-playbook playbooks/provision_pi_zero.yml --check --diff --ask-become-pass  # dry run
```

Use `-e pi5_ip=<ip>` / `-e zero_ip=<ip>` to override a target's address - NOT
`-e ansible_host=<ip>`, which is a global extra-var and would silently
re-target both hosts at once (breaking the Zero playbook's `delegate_to: pi5`
tasks: WiFi band lock, SSH-trust bootstrap).

## Notes

- systemd units under `src/systemd/*.service` are the single
  source of truth - Ansible substitutes their `__TARGET_USER__`/
  `__TARGET_HOME__` placeholders the same way the bash scripts' `sed` does,
  rather than duplicating them as `.j2` templates.
- The Pi Zero play locks the Pi 5's WiFi to its 2.4GHz BSSID for
  first-contact reachability, wrapped in `block`/`always` so the lock is
  released even if provisioning fails partway (a real gap in the bash
  version, which leaves it locked on a mid-script failure).
- `--check --diff` (`task rpi:ansible:check`) is a real dry run against an
  already-provisioned Pi - expect no changes if nothing has drifted.

## Carrying the calibrated `.env` across the restructure

The checkout lives at `~/vtitan` on both boards, and the `common` role brings it
to `repo_ref` in place: `gh repo clone` is `creates:`-guarded, so on a board that
already has one it does nothing and the `fetch` / `checkout` / `merge --ff-only`
below it do the work.

The one thing a checkout cannot carry itself is the real gitignored `.env`
(steering offsets, LiDAR yaw, Hailo model path). The 2026-09-10 restructure
dissolved `platform/` into `src/`, which moves `robot_dir` out from under it and
strands it at `platform/robot/.env` (`legacy_env_path` in
`inventory/group_vars/all.yml`). The role copies it across before the
`.env.example` fallback could stomp it.

### The removal this replaced, and why it was dangerous

Until 2026-09-13 the same block also removed an `old_repo_dir` once the `.env`
copy was confirmed, written for the 2026-07 `teamvoldemor -> teamvoltimor`
rename. **That rename renamed the GitHub org, not the checkout directory**, so
`old_repo_dir` was defined as `/home/{{ ansible_user }}/vtitan` - byte-identical
to `repo_dir`. Its guard was `old_repo_dir_stat.stat.exists and
final_env_stat.stat.exists`, with no comparison against `repo_dir`, so on any
board that already had a checkout and a landed `.env` it would have deleted the
live repo, including the calibrated `.env` just copied into it. Verified on
2026-09-13 that **both** Pis satisfied that guard. The removal is gone; only the
`.env` migration it wrapped survives.

The Pi 5 also had 5 sibling `git worktree` checkouts of other branches
(`vtitan-auto-annotator`, `-docs`, `-hailo`, `-hugo-docs`, `-platform`)
plus a stale manual `vtitan-session-backup` dir from an older rename.
All confirmed clean the same way - the `pi5` role removes them
(`old_worktree_dirs` in `inventory/group_vars/robot_pi5.yml`), leaving a single
`~/vtitan` checkout. Every entry there is a SIBLING of `~/vtitan`, never
`~/vtitan` itself. `deploy/ansible/` and `scripts/`
both live on `master` now, so nothing else needs that separate worktree -
`ANSIBLE_DIR`/`PLATFORM_SCRIPTS` in the root `Taskfile.yml` point straight
at `~/vtitan`.

The old `vtitan-*.service` units are **not** touched by provisioning -
they keep running side by side with the new `vtitan-*.service` ones until
you explicitly run `task rpi:cleanup:old-services` after confirming the new
services work. Don't skip this step: two services fighting over the same
GPIO/PWM/serial hardware is a real failure mode, not a theoretical one.

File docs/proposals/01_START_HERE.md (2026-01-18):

# 🚀 START HERE - WRO Future Engineers 2026 Proposals

**Last Updated:** 2026-01-17

Welcome! This guide will help you navigate all the proposal documents and make the best decision for your robot.

---

## 📋 What We've Organized

All proposals have been reorganized into clear categories:

```
proposals/
├── 01-start-here.md              ← YOU ARE HERE
├── README.md                      ← Folder structure overview
│
├── hardware/                      ← Hardware platform options
│   ├── README.md                  ← Complete hardware guide
│   ├── 01-motor-comparison.md
│   ├── 02-build-hat-motor-option.md
│   ├── 03-lego-dual-motor-build-hat.md
│   └── 04-hailo-calibration-guide.md   ← GPU calibration for AI HAT+
│
├── software/                      ← Software stack options
│   ├── README.md                  ← Complete software guide
│   └── 01-simulation-strategy.md       ← Testing with Gazebo
│
├── systems/                       ← Complete robot proposals
│   ├── 01-velocity-edge-ros2.md        (Jetson - NOT recommended)
│   ├── 02-minimalist-racer-classical.md (Fast but wastes AI HAT+)
│   ├── 03-cognitive-racer-vit.md        (Innovative ML approach)
│   └── 04-ros2-edge-racer-hybrid.md     (RECOMMENDED!)
│
└── comparisons/                   ← Decision tools & analysis
    ├── 01-proposal-comparison.md        (Full comparison matrix)
    ├── 02-technology-choices.md
    ├── 03-actual-hardware-analysis.md   (Your Klevor hardware!)
    └── 04-configuration-flexibility.md
```

---

## 🎯 Quick Start: 3-Step Decision Process

### Step 1: Understand Your Hardware

**Read:** `/hardware/README.md`

**Key Insight:** You have **Raspberry Pi 5 16GB + AI HAT+ 26 TOPS!**
- This is BETTER than what the original proposals assumed
- Don't waste money on Jetson Orin Nano!
- Use your existing Klevor hardware (100% reuse possible)

**New Hardware Cost:** $0-38 (depending on proposal)

---

### Step 2: Choose Your Software Approach

**Read:** `/software/README.md`

**Three main options:**

1. **ROS2 + YOLO (Proposal 4)** ⭐⭐ RECOMMENDED
   - Professional framework
   - YOLO on your AI HAT+ 26 TOPS
   - Flexible (Classical CV fallback)
   - Best balance of innovation + reliability

2. **Classical CV (Proposal 2)** ⭐ Fast but wastes AI HAT+
   - Fastest (200 Hz, 3.0 m/s)
   - Simplest development
   - ⚠️ Doesn't use your $70 AI HAT+ hardware!

3. **Vision Transformer (Proposal 3)** ⭐⭐ Most Innovative
   - Cutting-edge AI
   - Uses AI HAT+ 26 TOPS fully
   - Higher risk (ML training)
   - You already have Hailo CLIP experience!

---

### Step 3: Review Complete System Proposals

**Read:** `/systems/` folder

**Rankings (based on YOUR actual hardware):**

#### 🥇 #1: Proposal 4 - ROS2 Edge Racer
**File:** `systems/04-ros2-edge-racer-hybrid.md`

**Why #1:**
- ✅ Uses AI HAT+ 26 TOPS (YOLO inference)
- ✅ 100% hardware reuse
- ✅ Cost: $8 (optional color sensor)
- ✅ Professional ROS2 framework
- ✅ Balanced risk/reward
- ✅ 11-week timeline

**Best for:** Most teams - balanced approach

---

#### 🥈 #2: Proposal 3 - Cognitive Racer
**File:** `systems/03-cognitive-racer-vit.md`

**Why #2:**
- ✅ Uses AI HAT+ 26 TOPS fully (ViT)
- ✅ You already have Hailo CLIP experience!
- ✅ 100% hardware reuse
- ✅ Most innovative
- ⚠️ Higher risk (ML training)

**Best for:** Teams with ML expertise wanting cutting-edge innovation

---

#### 🥉 #3: Proposal 2 - Minimalist Racer
**File:** `systems/02-minimalist-racer-classical.md`

**Why dropped to #3:**
- ✅ Fastest (3.0 m/s, 200 Hz)
- ✅ Lowest risk
- ✅ Unique color sensor validation
- ❌ **WASTES your AI HAT+ 26 TOPS!**

**Modified recommendation:** Add YOLO backup to use AI HAT+

**Best for:** Speed-focused teams willing to add AI fallback

---

#### ❌ #4: Proposal 1 - Velocity Edge
**File:** `systems/01-velocity-edge-ros2.md`

**Why DON'T choose:**
- ❌ Requires Jetson ($500) when you have AI HAT+ 26 TOPS
- ❌ Only 60% reuse
- ❌ Makes no sense for your hardware

**Verdict:** Ignore this proposal!

---

## 🛠️ Supporting Documents

### Simulation Strategy
**File:** `software/01-simulation-strategy.md`

**What it covers:**
- How to use Gazebo simulator
- Test your code BEFORE building hardware
- Create WRO track in simulation
- Generate training data for ML
- Sim-to-real transfer strategies

**Why important:**
- Test 1000+ scenarios safely
- Faster iteration (10× vs real robot)
- Required for ML training (Proposal 3)
- Impressive journal content

**Timeline:** Start simulation in Week 1-2!

---

### Hailo GPU Calibration
**File:** `hardware/04-hailo-calibration-guide.md`

**What it covers:**
- How to calibrate AI models for Hailo AI HAT+
- GPU requirements (RTX 3060+, 32GB RAM)
- Calibration dataset (1000+ images)
- Step-by-step YOLO → Hailo workflow
- Expected performance (40-60 FPS YOLO!)

**Why important:**
- Required for Proposals 3 & 4 (AI-based)
- 10-50× faster with GPU vs CPU
- Proper calibration = <1% accuracy loss

**Timeline:** Needed in Weeks 5-6 (after training)

---

## 📊 Comparison Tools

### Main Comparison Matrix
**File:** `comparisons/01-proposal-comparison.md`

**66-page comprehensive comparison** including:
- Side-by-side feature comparison
- Updated rankings based on YOUR hardware
- Decision matrices
- Scenario-based recommendations
- Cost breakdowns
- Risk analysis

**Read this if:** You want ALL the details

---

### Your Actual Hardware Analysis
**File:** `comparisons/05-actual-hardware-analysis.md`

**What changed:**
- Original: Hailo-8L (13 TOPS) + Pi5 8GB
- **Actual: AI HAT+ 26 TOPS + Pi5 16GB!** ⭐⭐

**Impact:**
- Proposals 3 & 4 jumped to #1 and #2
- Proposal 1 (Jetson) is now wasteful
- You can run larger models faster!

---

## 🎓 Learning Path

### For Beginners
1. Read `/hardware/README.md` (understand your hardware)
2. Read `/software/README.md` (understand software options)
3. Read `systems/04-ros2-edge-racer-hybrid.md` (recommended proposal)
4. Read `11-simulation-strategy.md` (how to test)
5. Start building!

### For ML Enthusiasts
1. Read `comparisons/05-actual-hardware-analysis.md` (your AI HAT+ power!)
2. Read `systems/03-cognitive-racer-vit.md` (ViT proposal)
3. Read `12-hailo-calibration-guide.md` (how to use AI HAT+)
4. Read `11-simulation-strategy.md` (RL training in Gazebo)
5. Start collecting data!

### For Speed-Focused Teams
1. Read `systems/02-minimalist-racer-classical.md`
2. **IMPORTANT:** Add YOLO backup to use AI HAT+ (don't waste it!)
3. Read `11-simulation-strategy.md` (test HSV CV)
4. Start building for speed!

---

## 🚦 Decision Flowchart

```
START
  |
  ├─ Do you have ML/PyTorch experience?
  │   ├─ YES → Proposal 3 (Cognitive Racer - ViT)
  │   └─ NO → Continue
  |
  ├─ Do you want to learn professional ROS2?
  │   ├─ YES → Proposal 4 (ROS2 Edge Racer) ⭐ RECOMMENDED
  │   └─ NO → Continue
  |
  ├─ Is maximum speed your #1 priority?
  │   ├─ YES → Proposal 2 (Minimalist) + ADD YOLO backup
  │   └─ NO → Proposal 4 (ROS2 Edge Racer) ⭐ DEFAULT
```

---

## ⚡ TL;DR - Just Tell Me What to Do!

### RECOMMENDED: Proposal 4 - ROS2 Edge Racer

**Configuration:**
```yaml
Hardware:
  - Raspberry Pi 5 16GB (from Klevor)
  - Hailo AI HAT+ 26 TOPS (from Klevor)
  - RPi Camera Module 3 Wide (from Klevor)
  - RPLiDAR C1 (from Klevor)
  - BNO08X IMU (from Klevor)
  - 2× VL53L0X (from Klevor)
  - Pico 2W (from Klevor)
  - TCS34725 color sensor (NEW - $8)

Software:
  - ROS2 Humble
  - YOLOv8-Nano on Hailo AI HAT+ (30-60 FPS)
  - Classical HSV CV (fallback, 120 FPS)
  - TCS34725 physical validation
  - 50 Hz control loop

Timeline: 11 weeks
Cost: $8
Reuse: 100% base hardware
Win Probability: ⭐⭐⭐⭐⭐
```

**What to do RIGHT NOW:**

1. **Week 1:** Read full proposal (`systems/04-ros2-edge-racer-hybrid.md`)
2. **Week 2:** Set up simulation (`11-simulation-strategy.md`)
3. **Week 3:** Install ROS2 on Pi5
4. **Week 4:** Test sensors in simulation
5. **Week 5:** Collect training data (1000+ images)
6. **Week 6:** Train YOLO & calibrate with Hailo (`12-hailo-calibration-guide.md`)
7. **Weeks 7-11:** Build, test, iterate!

---

## 📞 Need Help?

### If you're confused about...

**Hardware choices:**
→ Read `/hardware/README.md`

**Software frameworks:**
→ Read `/software/README.md`

**Which proposal to choose:**
→ Read `comparisons/01-proposal-comparison.md`

**How to use your AI HAT+:**
→ Read `12-hailo-calibration-guide.md`

**How to test without hardware:**
→ Read `11-simulation-strategy.md`

**Everything at once:**
→ Start with THIS file (01-start-here.md) and follow the Learning Path above!

---

## ✅ Next Steps

- [ ] Read recommended proposal (Proposal 4)
- [ ] Review simulation strategy
- [ ] Review Hailo calibration guide
- [ ] Order TCS34725 color sensor ($8)
- [ ] Set up desktop GPU machine (for Hailo calibration)
- [ ] Install Gazebo + ROS2 (for simulation)
- [ ] Start building! 🚀

---

**Good luck with WRO Future Engineers 2026!**

**Your hardware is excellent - use it wisely!** 💪🤖

---

## 📄 Document Map

Quick reference to all files:

| File | Purpose |
|---|---|
| `01-start-here.md` | **YOU ARE HERE** - Navigation guide |
| `README.md` | Folder structure overview |
| `/hardware/README.md` | Complete hardware options guide |
| `/software/README.md` | Complete software options guide |
| `/systems/04-ros2-edge-racer-hybrid.md` | **RECOMMENDED PROPOSAL** |
| `/systems/03-cognitive-racer-vit.md` | Alternative: ML/ViT approach |
| `/systems/02-minimalist-racer-classical.md` | Alternative: Speed-focused |
| `/systems/01-velocity-edge-ros2.md` | ❌ Don't choose (Jetson) |
| `/comparisons/01-proposal-comparison.md` | Full comparison matrix |
| `/comparisons/03-actual-hardware-analysis.md` | Your Klevor hardware analysis |
| `software/01-simulation-strategy.md` | Gazebo simulation guide |
| `hardware/04-hailo-calibration-guide.md` | GPU calibration for AI HAT+ |

**Total pages:** ~250+ pages of comprehensive analysis!

**Time to read everything:** 4-6 hours
**Time to read essentials:** 1-2 hours (this file + Proposal 4 + Simulation + Hailo)

---

**Happy building! 🎉**

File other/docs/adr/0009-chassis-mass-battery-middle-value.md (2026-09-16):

# 0009. Chassis mass is the middle of the battery configurations

- Status: superseded by 0077
- Superseded by: 0077
- Date: 2026-09-07
- Commit: a23d725a

## Context

The assembled car weighs about 1.51 kg with the practice battery (Deans) and about
1.46 kg with the competition battery (XT60 shorty), connectors included
(2026-09-07). The URDF and the Gazebo model sum `chassis.mass` with four wheel
masses to get the total.

## Options considered

- (a) Use the practice-battery mass.
- (b) Use the competition-battery mass.
- (c) Use one deliberate middle value.

## Decision

(c). `chassis.mass = 1.3` kg is the chassis body ALONE, because the consumers sum
it with four wheel masses: 1.3 + 4 x 0.05 = 1.5. That is a deliberate middle value
between both battery configurations, so the simulation never under-predicts
required torque.

## Consequences

- Change chassis and wheel mass together, or the simulated car stops weighing what
  the real one does.
- Mass drives the inertia tensors, so the choice reaches the dynamics.

## Superseded by 0077

Replaced by [0077](0077-power-rails-and-chassis-mass.md): Power rails are sized to
measured load and the chassis mass is the battery midpoint.

The successor carries the current decision and its rationale; this file keeps
the original decision above so the supersede chain stays readable.

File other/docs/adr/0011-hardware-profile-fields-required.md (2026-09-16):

# 0011. Swappable servo and motor limits live in the hardware profile

- Status: superseded by 0070
- Superseded by: 0070
- Date: 2026-08-11
- Commit: d2f821ce

## Context

`servo_max_angle_deg`, `max_wheel_angle_deg`, `max_speed_mps`, `max_accel_mps2`
and `speed_response_tau_s` describe a specific servo or motor, not the chassis.
They used to be declared in `robot.toml` (the Injora's 90/55, and one shared
accel/lag value of 2.0), which meant a run with no profile set silently modelled
whichever servo happened to be checked in rather than the one on the robot. That
is not hypothetical: a whole night of motor tests once ran on the unmodified base
ceiling because `VTITAN_HARDWARE_PROFILE` was blank, and there is no way to tell
from behaviour alone which config a run used.

`max_speed_mps` is a hard ceiling, not a tuning knob: `AckermannKinematics` clamps
to it, which is why a speed profile capping commands at 0.30 m/s once turned out
to be completely inert (both 0.30 and 0.50 saturate against it). Since 2026-08-21
the navigation speed ladder is absolute m/s, so raising this value only clamps and
delivers nothing until the motor profile's own `motion/speed.toml` raises the
tiers too. `max_accel_mps2` and `speed_response_tau_s` were removed from here for
the same reason: a bag showed the current motor nowhere near the shared 2.0.

## Options considered

- (a) Keep defaults in `robot.toml` for the components on hand.
- (b) Make the fields absent there and require a named profile.

## Decision

(b). The fields live in the selected component profile under `config/profiles/`
(`180deg-injora-14kg` or `270deg-hiwonder-35kg` for servos), and one must be named
in `VTITAN_HARDWARE_PROFILE`. Loading fails with a message listing the candidates
if none is. What stays in `robot.toml` is everything true of the CHASSIS
regardless of which servo drives it. Everything upstream (`/ackermann_cmd`, the
navigator, the simulator) speaks WHEEL angles per the ROS convention; only the
servo speaks servo angles, and `linkage_ratio` is derived from the two profile
fields rather than declared.

## Consequences

- A missing profile is a loud load-time error instead of a silent wrong model.
- Raising `max_speed_mps` alone does nothing until the speed tiers rise too.
- `max_accel_mps2` and `speed_response_tau_s` moved out after the 2026-08-29 bag.

## Superseded by 0070

Replaced by [0070](0070-hardware-profiles-and-challenge-overlays.md): Hardware profiles
are per-component overlays and a wrong name fails loud.

The successor carries the current decision and its rationale; this file keeps
the original decision above so the supersede chain stays readable.

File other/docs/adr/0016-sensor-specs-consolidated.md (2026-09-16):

# 0016. Sensor specs are consolidated into robot.toml

- Status: superseded by 0069
- Superseded by: 0069
- Date: 2026-07-30
- Commit: f6d53ac9

## Context

Several sensor specs were hand-maintained in more than one language or file.
`lidar.min_range` sat in a hand-maintained Python constant that stated 0.05
(measured ~45 mm); `lidar.max_range` was a hand-maintained Python constant
(`LIDAR_MAX_RANGE`). `imu.mount_z_offset` (0.01 m) was duplicated as
`simconfig.RobotImuZOffset` (Go, correct, since removed: `simconfig.Robot` now
carries it loaded from `robot.toml`), a hardcoded 0.01 in
`src/python/ros2_ws/src/vtitan_bringup/launch/static_tfs.launch.py` (correct),
and the URDF xacro's `imu_link` joint origin
(WRONG, hardcoded to 0, i.e. the IMU was not actually placed there). The LIDAR
z-offset was similarly triplicated (see ADR 0014).

## Options considered

- (a) Leave each consumer's constant in place and keep them aligned by hand.
- (b) Consolidate the hardware description in `robot.toml`.

## Decision

(b). A sensor spec belongs with the rest of the hardware description, not beside
the simulation parameters or duplicated per consumer. `lidar.min_range = 0.045`
(measured ~45 mm), `lidar.max_range = 12.0`, and `imu.mount_z_offset = 0.01` live
here, consolidated 2026-07-30.

## Consequences

- The xacro's wrong `imu_link` origin (0) is fixed by reading the one value.
- The distinction that matters for `min_range` is that anything nearer is
  unmeasurable rather than clear, which matters when the chassis works within a
  few centimetres of a surface (parking, wall contact, escape).

## Superseded by 0069

Replaced by [0069](0069-config-governance.md): Config values live in TOML, descriptions
in schemas, rationale in ADRs.

The successor carries the current decision and its rationale; this file keeps
the original decision above so the supersede chain stays readable.

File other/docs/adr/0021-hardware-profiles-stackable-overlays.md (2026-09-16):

# 0021. Hardware profiles are stackable partial overlays

- Status: superseded by 0070
- Superseded by: 0070
- Date: 2026-08-11

## Context

A 270 degree servo gives roughly 85 deg of road-wheel travel against the
current build's bench-measured ~55 deg. Swapping the servo is trivial, but the
tuning built around that geometry (corner arc ceiling, speed ladder, pursuit
lookahead and thresholds) was hand-tuned and hardware-validated for 55 deg, and
must not be silently recomputed from the new geometry. The mechanism has to let
alternate tuning live beside the base config without branching on servo angle
anywhere in the code.

## Options considered

- (a) A full standalone copy of every config file per profile
      (`profiles/servo270/robot.toml`, `.../navigation/**`, ...).
- (b) A profile is a partial override holding only the keys that differ from
      base, selected as an ordered, stackable list.

## Decision

(b). `VTITAN_HARDWARE_PROFILE` names a comma-separated, ordered list of
profiles. Each profile is a file tree under `profiles/<name>/` containing only
the keys it changes, deep-merged left to right onto the base
(`base <- profile[0] <- profile[1] <- ...`, later names winning). The base TOML
is untouched in place. A profile combining a servo variant with an independent
track-geometry variant is just two names in the list.

Profiles whose numbers are not yet benchmarked are seeded empty or verbatim
from base, marked `# TODO(...): needs bench/track validation`, never with
invented values. The build uses one live combination at a time.

## Consequences

- Servo and motor limits can change without editing the chassis config, and no
  navigation code reads a servo angle to decide behaviour.
- A profile that omits a required component fact is a loud load-time error (ADR
  0011), not a silent zero.
- Overlay keys are merged by file path, so a profile cannot yet move a key
  between files without a loader change (see ADR 0070).

## Superseded by 0070

Replaced by [0070](0070-hardware-profiles-and-challenge-overlays.md): Hardware profiles
are per-component overlays and a wrong name fails loud.

The successor carries the current decision and its rationale; this file keeps
the original decision above so the supersede chain stays readable.

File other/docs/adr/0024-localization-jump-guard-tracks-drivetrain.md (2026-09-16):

# 0024. The localization jump guard tracks the drivetrain ceiling

- Status: superseded by 0084
- Superseded by: 0084
- Date: 2026-08-29

## Context

`localization.MAX_SPEED_MPS` is an implausible-jump guard: a LIDAR pose update
implying more than this is discarded and the prior pose kept. It shipped at
0.25, sized against the retired motor's 0.156 m/s ceiling, and was never raised
when the profile changed. The current drivetrain measures about 0.58 m/s
closed-loop and ~0.9 m/s open-loop at the 2026-08-29 bench, so the gate sat
below the speeds the robot actually reaches and silently froze pose whenever it
drove quickly.

That was not just a localization bug, it invalidated a measurement: pose was
used as the independent check on encoder distance. On `run_20260829_003233` the
two agreed to 0.5 percent (28.46 m encoder against 28.62 m pose), and both were
under-reporting -- the encoder because `counts_per_rev` was too high, pose
because updates past 0.25 m/s were being thrown away. Two suppressed
measurements agreeing is not corroboration.

## Options considered

- (a) Keep the static 0.25 bound.
- (b) Raise the guard with the drivetrain, at a fixed headroom over the measured
      ceiling.

## Decision

(b). The guard is raised to about 1.5x the measured closed-loop ceiling, and
raised again whenever the drivetrain gets faster. It is a speed bound, not a
quality threshold; the relocalization path (ADR 0025) handles a pose that is
genuinely wrong.

## Consequences

- The guard no longer defers honest scan-match corrections at speed.
- A stale `MAX_SPEED_MPS` silently invalidates any comparison of encoder and
  pose odometry, so it must move with every motor or speed-profile change.

## Superseded by 0084

Replaced by [0084](0084-localizer-divergence-and-relocalization.md): Pose divergence is
detected off-track and recovered by armed global relocalization.

The successor carries the current decision and its rationale; this file keeps
the original decision above so the supersede chain stays readable.

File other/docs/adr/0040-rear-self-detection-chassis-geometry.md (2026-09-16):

# 0040. The rear self-detection filter follows chassis geometry

- Status: superseded by 0056
- Superseded by: 0056
- Date: 2026-09-06

## Context

One scalar self-detection threshold cannot describe the rear: the chassis
boundary runs from 0.137 m at the rear sector's edges to 0.2722 m straight back,
and 0.08 m is inside the body everywhere in between. Measured on
`run_20260906_192424` the rear minimum was the ROBOT on 100 percent of scans
(-157 deg / 0.125 m, -172 deg / 0.187 m), so `most_constrained_side` read BACK on
84 percent of driving ticks. There is no BACK escape branch, so no maneuver was
ever generated: 212 ticks of `escape_risk=critical` across the five pillar
contacts produced zero escapes.

## Options considered

- (a) Filter the rear sector's self-detection with the single scalar.
- (b) Gate it by the chassis geometry at each bearing.

## Decision

(b). `rear_self_detection_from_chassis` ships true. It is a `default` tag, so a
TOML that omits the key reads the shipped value rather than silently reverting
the filter to the scalar through the zero value.

## Consequences

- The rear sector stops mistaking the robot's own body for an obstacle, so the
  escape machinery can see real rear threats.
- Mirrors the same trap class as `corner_arc_assume_wide` and
  `min_history_for_distance`: an omitted key must not silently change behaviour.

## Superseded by 0056

Replaced by [0056](0056-raw-and-masked-scan.md): The scan is read twice, raw for speed
and masked for the escape.

The successor carries the current decision and its rationale; this file keeps
the original decision above so the supersede chain stays readable.

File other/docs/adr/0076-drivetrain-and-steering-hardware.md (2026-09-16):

# 0076. The drivetrain is sized on measured current, and calibration is never inherited

- Status: accepted
- Date: 2026-09-15
- Supersedes: 0010, 0030

## Context

The traction branch measured about 10 A sustained at 50 percent duty and peaks
near 20 A, against the L298N's 2 A per channel: the old H-bridge was not failing,
it was operating at an order of magnitude over its specification, which produced
brownouts and heating. The Pi Zero 2 W SoC also has exactly two hardware PWM
generators, and a floating H-bridge enable line spun the motor at full reverse
with no software running.

Encoder calibration had similar silent failures: a motor swap invalidated every
constant derived from motor physics, and an unset hardware profile modelled
whichever servo happened to be checked in.

## Options considered

- (a) Keep the L298N, share one PWM channel, inherit encoder constants, and rely
      on passive pull-downs.
- (b) Size the H-bridge on measured current, allocate the scarce PWM engines
      deliberately, sequence enables and drive the GPIO actively, and require
      per-motor calibration.

## Decision

(b). The BTS7960 (43 A, MOSFET, low drop) replaces the L298N; after the swap the
weakest link is the power switch, whose conduction capacity is still unmeasured.
The harness uses genuinely independent RPWM and LPWM with `R_EN` and `L_EN`
permanently HIGH: direction is selected by which channel carries duty. The servo
uses hardware PWM on GPIO12 (absolute position, jitter-intolerant); forward drive
uses the one free hardware engine on GPIO13 (frequent, performance-critical);
reverse rides software PWM on GPIO26 because only parking and recovery use it and
it tolerates jitter. One `pwm-2chan` overlay exports both hardware channels.

`R_EN`/`L_EN` gate the module's overcurrent/thermal protection, not direction.
The physical BCM pin versus the module's own R_EN/L_EN silkscreen no longer
matters because both are always HIGH; it mattered only under the old
shared-PWM / EN-toggle design.

Enables are asserted only after both PWM channels are confirmed at 0 duty; the
GPIO lines are actively driven low (`op,dl`, not the ineffective `pd`), re-driven
on service exit via `ExecStopPost`, and re-driven on driver disconnect, because a
plain stop once reproduced full-speed reverse. A physical pull-down on LPWM is the
complete fix and is still not installed.

`counts_per_rev` and `max_rpm` are required fields, never inherited across a motor
swap. `max_duty = 0.5` caps closed-loop drive duty. Steering facts stay physical:
`max_wheel_angle_deg` is the bench-measured linkage travel and must never be
lowered as a tuning action; `steering_limit_deg` is the navigator's policy, and a
validator rejects a limit above the physical maximum (see 0050). `servo_slew_rate_rad_s
= 2.4` is a loaded bench measurement and must not be read from the steering-
position topic, which is only an echo of the command.

`max_steering_rate` is the cornering policy, not the hardware model: lowered 2.0
to 1.2 rad/s on 2026-08-28 and still binding 8.2 to 13.1 percent of driving
ticks, while `servo_slew_rate_rad_s` budgets the bay pause. The bay servo pause
is 50 ticks (2.50 s) per reversal at 1.2 rad/s, cut to 25 (1.25 s) once 2.4
replaced it; the measured exit duration fell 30.5 to 5.3 s over the same change
at unchanged net rotation, so the tick budget and the exit duration are the same
change at two scales (reconciled against `src/config/navigation/motion/pursuit.toml`,
which ships `servo_slew_rate_rad_s = 2.4`).

Reverse is about 40 percent slower than forward at identical duty (336.6 against
193.7 deg/s), attributed to brushed-motor timing advance, so escape reverse bursts
travel less than a symmetric model predicts.

## Counter-phase four-wheel steering

The chassis must approach a 90 degree per-wheel turn to make the parking-bay exit
viable and to take the tight Obstacles corners; a car-like Ackermann linkage was
the alternative. Steering a four-wheel-drive chassis also loads the servo far
more than a two-wheel front steer, which is why the steering servo was upgraded
from 14 kg-cm to 35 kg-cm.

Both axles steer in opposite directions by the same 1:1 angle
(`rear_steer_ratio = 1.0`). The effective wheelbase for the kinematic model
becomes `wheelbase / (1 + rear_steer_ratio) = wheelbase / 2`, because the vehicle
yaws about twice as fast as a front-steer car at the same steering angle. The
chassis delivers about 0.55 of the yaw a bicycle model predicts, compensated
separately (`obstacles_yaw_gain_compensation = 0.55`). Measured minimum turn
radius is 0.29 m. The 270 degree servo (Hiwonder HPS-3527SG) replaced the 180
degree Injora because counter-phase steering needs the extended travel to
approach the 90 degree per-wheel turn.

The turning radius is roughly halved and the bay exit becomes feasible. Any gain
fitted against a front-steer model is too hot for the real chassis, so the
simulator had to be corrected to counter-phase before its numbers meant anything
(pre-4WS: old sim minimum turn 0.329 m against the actual 0.165 m, collisions
7/16 to 16/16, timeouts 9/16 to 0/16). The explicit quantitative
Ackermann-versus-counter-phase comparison is still missing from the shipped docs.

This section absorbs 0075; the steering geometry and the drivetrain it sits on
are one story.

## Consequences

- The H-bridge operates within spec and the boot spin is removed.
- A motor swap cannot silently reuse another motor's numbers.
- The PWM allocation is a deliberate use of a scarce resource, not an accident.
- Open residual risks: no physical LPWM pull-down; the feedback sign is
  inconsistent with the command sign under a reversed drive; reverse asymmetry has
  not been re-measured since the motor swap.

## History

- 6732680d 2026-07-25: characterise the drive motor on battery power. Deadband
  below about 0.7 m/s; reverse asymmetry 336.6 against 193.7 deg/s.
- c81625c3 2026-07-25: calibrate encoder counts_per_rev against measured travel
  (194 to 676). Duty-based calibration abandoned (43 against 54 cm).
- bddcdf52 2026-07-25: drive the steering servo from hardware PWM to stop jitter.
- dc4051ce 2026-07-28: move the drive motor PWM to hardware sysfs, off gpiozero
  software PWM; switch to `pwm-2chan`.
- b238de37, e78e7fe2, 3b2571cd 2026-08-25: split drive from encoder, add the
  BTS7960 backend, fix R_EN/L_EN pins, make encoder calibration required.
- a67345a9 2026-08-26: the master change to independent RPWM/LPWM (bundled inside
  a nav commit; the branch twin is 6aee1ac2).
- 7ce5f207, f5797c6a, 96020000, 873a1232, 9748b30d, d8791b89 2026-08-27/28: drive
  the GPIO low from earliest boot (`op,dl` refutes `pd`), re-drive on exit and
  disconnect, template the pins, and assert enables only after 0 duty.
- 8fccb633 2026-08-27: flip `drive.reversed` for the BTS7960 rewire.
- 51c9f914 2026-08-27: cap closed-loop drive duty at 50 percent after the motor
  swap.
- 4f254ef4 2026-08-28: recalibrate the encoder (676 to 86, 42.5 to 123) and rescale
  PID gains about 8x.
- 1913975c, 958011fa 2026-08-29: counts_per_rev 86 to 60, live-verified.
- bbf9660d and 27146f7a 2026-08-29: raise max_rpm so the feedforward stops
  saturating (123 to 175 to 348); add the duty deadband (`rpm = 434.6*duty - 86.7`).
- d47b1cbe 2026-08-29: split encoder calibration into per-motor profile overlays.
- bbd6803f 2026-08-30: raise the speed ladder for the new motor.
- 654e57e6 2026-09-02: `max_speed_mps = 0.58` measured, not the feel-based 1.0.
- 0fecf09a and 73693f53 2026-09-11: split the servo's real slew rate from the
  command rate limiter; 2.4 rad/s measured (bay exit 30.5 to 5.3 s).
- 2026-09-11 loaded bench derivation: the wheel stopped about 20 deg short of the
  far lock at a 0.90 s hold, so 150 deg in 0.90 s is 2.91 rad/s (about 1.02 s
  full swing; about 2.9 rad/s over the 170 deg lock-to-lock). 2.4 leaves 23
  percent margin over the measured swing, while 2.9 leaves 3 percent on a 20 deg
  read by eye and would under-budget the bay pause and dead-reckon an angle not
  reached. `max_wheel_angle_deg` multiplies into the same swing and is itself
  unverified.
- `/motor/steering_position` is an echo (slope 180/pi, lag 0, R^2 = 1.000000),
  so no bag can settle the rate; the gyro gives only a lower bound of about 1.27
  rad/s at p90.
- 2026-08-28: `run_20260828_220533` showed the controller saturating
  `max_steering_rate` at hard corners (0.6 rad = rate x 0.3 s window). Past sim
  sweeps only tested RAISING it (1.5x and 3.0x, both worse, 107 against 114); the
  lowered exact value is untested.
- 8eb3c38e 2026-07-25: model the chassis as counter-phase four-wheel steer, not
  front only. Moves the ICR to the chassis centre; 20 deg steer gives 0.261 m
  radius against the old 0.522 m.
- 77962720 2026-07-25: flag the sign-avoidance log as stale after the model change.
- d7579db7 2026-08-15: pin the counter-phase geometry; 6 tests, reverting
  `_turn_reference_len` fails 2 of 6.
- 6a89c45f 2026-08-22: make the Gazebo URDF a counter-phase 4WS car (rear links
  mimic `x-1.0` of front).
- 7a96dd6a 2026-09-05: compensate pure pursuit for the delivered yaw; Go had no
  compensation and turned about 1.8x too wide. Obstacles sighted laps>=3 60 to 111.
- 72e7172b 2026-09-07: ship the measured turn radius 0.29 m.
- 3b330a1c and 878b8485 2026-09-14: document the trade-offs and catalogue the
  rejected Ackermann diagram.
- Feedforward fit is R^2 0.9999 over three points at duty 0.5/0.75/0.9; the duty
  deadband starts at 0.200 and `max_rpm` 348 at duty 1.0. The stale 86 counts/rev
  calibration read the drive ceiling as about 0.45 m/s against the measured 0.58.
- SpeedEstimator window: bench data of 2026-08-28 at 86 counts/rev and a 13.6 rpm
  target averages about 0.39 counts per 20 ms tick (over 100 percent relative
  swing), so the 0.1 s window averages about 1.95 counts and makes a +-1 count
  about a 50 percent rather than a >100 percent swing.
- Servo twitch investigation: the twitching persisted under a single command with
  no PWM rewrites and on a fresh battery, ruling out both command traffic and
  supply sag.
- The old EN-first BTS7960 ordering produced brief real motor kicks on both a cold
  boot and a warm reconnect.
- The retired profile shipped `speed_response_tau_s = 0.0` (instant response); the
  2026-08-29 calibration put tau at 0.35 measured against `run_20260829_140424`,
  leaving the suite with `yaw_gain` calibrated but tau not until the pin moved.
- The committed Gazebo URDF did not parse: `--` inside XML comments made
  `xacro.process_file` raise ExpatError, killing every Gazebo launch that depended
  on the robot description.
- `max_speed_mps` progressed 0.234, then an estimated 1.0, then 0.58 at the
  2026-08-30 bench.
- Creep stall was fine-binned 0.10 to 0.22 m/s in 0.01 steps: stall was 73.8
  percent in the 0.09 to 0.11 m/s bin and 2.1 percent by 0.15 to 0.20. The heading
  limiter floors speed to the creep tier and binds on 57.1 percent of corner ticks,
  so the corner slow-down and the corner stall are the same event at that floor.
- The minimum deliverable speed rises with steering load: stall was 0.2 percent
  straight against 19.4 percent at full lock, so a single creep floor overpays on a
  straight and still stalls at lock.
- At creep speeds the chassis delivers only 0.43 to 0.84 of the commanded speed
  while the simulator tracks its command almost exactly.
- `_guarded_command`'s `v * tau` stopping budget cannot be checked against bags:
  the whole 200-bag archive (2026-09-10) held only 15 clean coast episodes, and the
  budget saturates when the command returns before the wheel stops. This wants a
  bench test, not more bags.
- The escape commands 44 deg and lasts a median 0.49 s; the shipped 1.2 rad/s
  predicts 0.64 s to reach it, so the escape extracts only 10.5 deg of rotation,
  leaves pointing where it entered and re-approaches the same pillar after 2 to 8
  cm. A real 35 kg servo is about 5 rad/s.
- The predecessor wheel-angle constant was wrong by 1.28x.
- The echoed-command test is to run the same step-response fit on
  `/motor/steering_position` (candidate) and `/motor/drive_speed` (encoder
  control): a lag-0, R^2 about 1, zero-residual candidate against a lagged control
  proves the candidate is the command echoed back.

## Cross-references

- 0010 and 0030 are superseded; their decisions are carried above.
- 0050 owns the escape steering angle policy in physical units.
- 0070 owns the profile overlays that hold per-motor calibration.
- 0060 owns the bay exit that rides on the servo slew rate.
- 0075 is deprecated and merged into this ADR; 0052 owns the pursuit law that
  consumes the effective wheelbase, and 0054 owns the yaw model.

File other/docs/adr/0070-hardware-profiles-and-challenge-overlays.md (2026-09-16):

# 0070. Hardware profiles are per-component overlays and a wrong name fails loud

- Status: accepted
- Date: 2026-09-15
- Supersedes: 0011, 0021

## Context

A robot without a profile selected silently modelled whichever servo happened to
be checked in, not the one on the robot. That is not hypothetical: a whole night
of motor tests ran against the unmodified base ceiling because
`VTITAN_HARDWARE_PROFILE` was blank, and there is no way to tell from behaviour
alone which config a run used. A profile folder was also misnamed
(`servo270` against the active name), and the loader skipped a missing overlay
silently, so the 270 degree servo range never applied and every drive test that
night ran on the base ceiling. A silently inactive or silently misnamed profile
looks identical to a robot correctly running on unmodified defaults.

The chassis facts and the component facts were also mixed in one file, so
swapping a servo risked silently recomputing the tuning that had been
hand-validated for the old geometry.

## Options considered

- (a) One chassis file with component facts inline; profiles as full files.
- (b) Component facts only in selected component profiles, combined as ordered
      stackable partial overlays, with a loud load-time error on a missing or
      malformed profile.
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

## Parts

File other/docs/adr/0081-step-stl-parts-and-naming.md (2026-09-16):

# 0081. Every 3D part is published as STEP and STL with kebab-case names

- Status: accepted
- Date: 2026-09-15

## Context

SolidWorks part names (uppercase, spaces, `ñ`, decimal commas) break URLs, shell
globs and clones onto non-UTF-8 filesystems, and the repository could not tell
which of two parts came first because they were all published in one commit.
GitHub renders STL in an interactive viewer and does not preview STEP at all, so
vTitan's own CAD was the unviewable format.

## Options considered

- (a) Publish one format per part, with the original designer names.
- (b) Publish STEP for fabricating and STL for printing and viewing, with one
      normalized kebab-case stem per part.

## Decision

(b). Each part ships as `.step` (exact B-rep, editable in CAD, not previewed by
GitHub) and `.stl` (triangle mesh, printable, rendered by GitHub). A part that
exists in both formats carries the SAME stem in both, so they pair at a glance.
Names are kebab-case ASCII with a lowercase extension.

The suffix grammar is fixed: `-vN` is an ordered iteration (the last is the one
printed), `-vN.M` is a minor retouch of `vN`, and a descriptive suffix (`-cajera`,
`-arrastre`, `-con-eje`) is a coexisting variant, not an iteration. The old names
`-max`, `-ultimate`, `-nuevo`, `-editado`, `-ligero` were replaced by `-vN`
because they are not orderable.

## Consequences

- A judge can spin an STL in the browser; a builder can reopen the STEP.
- 17 of 29 `.step` files pair with a same-name `.stl`; the other 12 are purchased
  components.
- The print-parameter manifest (material, layer height, infill, supports) is still
  missing.

## History

- a76de71c 2026-09-06: import the old and current 3D models under SolidWorks names.
- 3a73ff3a 2026-09-08: move `3d-models/` to `models/` and detector weights to
  `ml-models/`.
- 3b330a1c 2026-09-14: rename 90 of 120 files to kebab-case (42 with `ñ`/`ó`, 2
  decimal commas, 72 extension case).
- 878b8485 2026-09-14: publish the STL exports renamed to match the `.step` stems;
  add the READMEs.
- 30e8d633 2026-09-14: version the filenames (`-vN`), delete a duplicate STL,
  correct counts.
- a9539e66 2026-09-14: name the model folders after the robots.
- bfdea298 2026-09-14: recompress the blueprints (3308 KB to 2496 KB).
- aae2ab4e 2026-09-14: identify the 50-tooth motor pulley.

## Refuted

- The "48 STL" count; "(PNG y WebP)"; the stale "15 cm/s" motor identity.

## Cross-references

- 0082 owns the wiring harness scheme, the other hand-authoring choice.

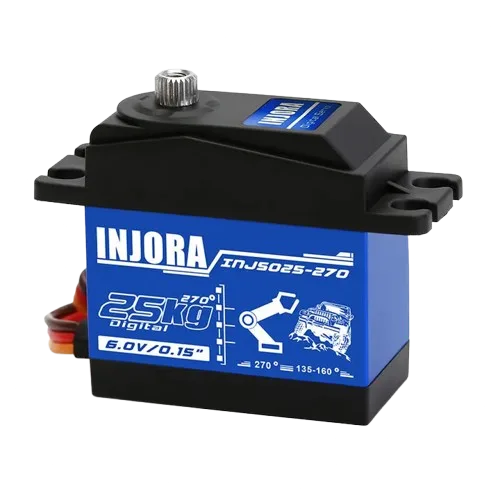
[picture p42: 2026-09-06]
other/assets/images/components/injora-14kg-injs014-micro-servo.webp

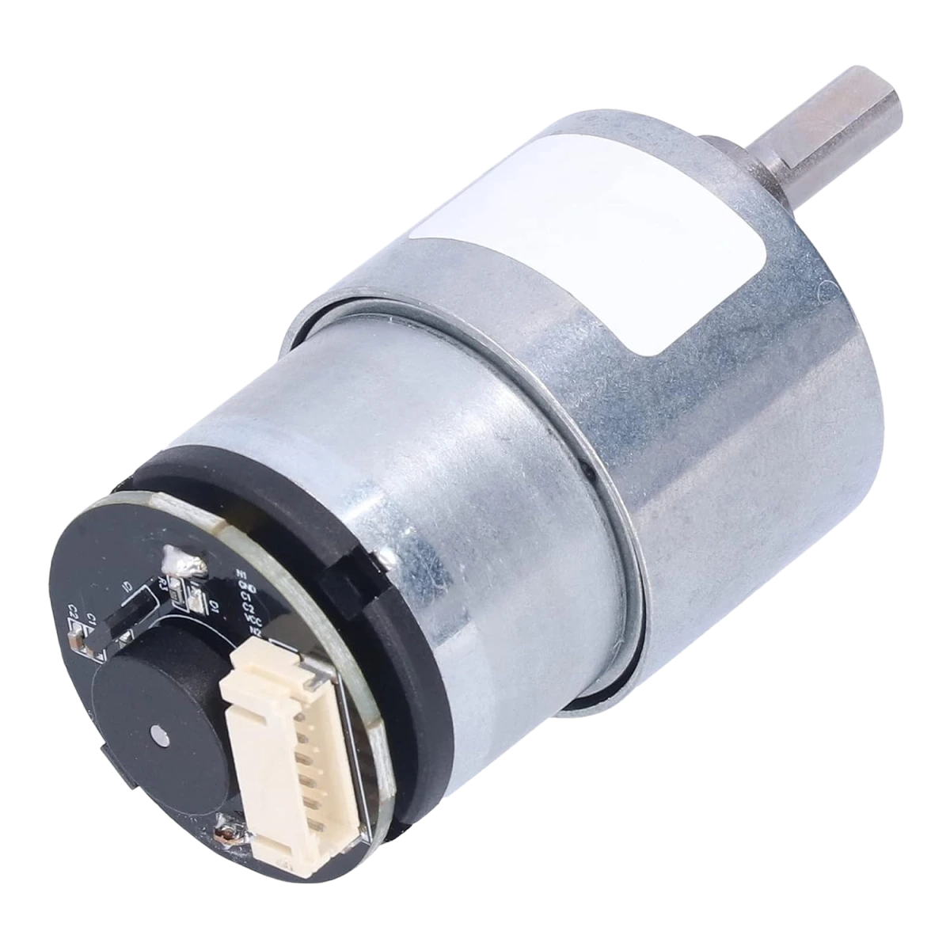
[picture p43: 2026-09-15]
other/assets/images/components/generic-motor-1500rpm.webp

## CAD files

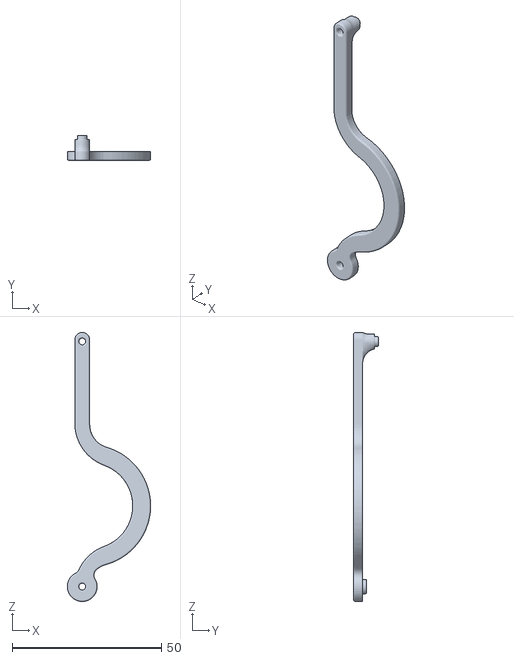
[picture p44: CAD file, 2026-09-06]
models/klevor/stl-files/vastago-de-direccion.stl
27.9 x 8.25 x 90.0

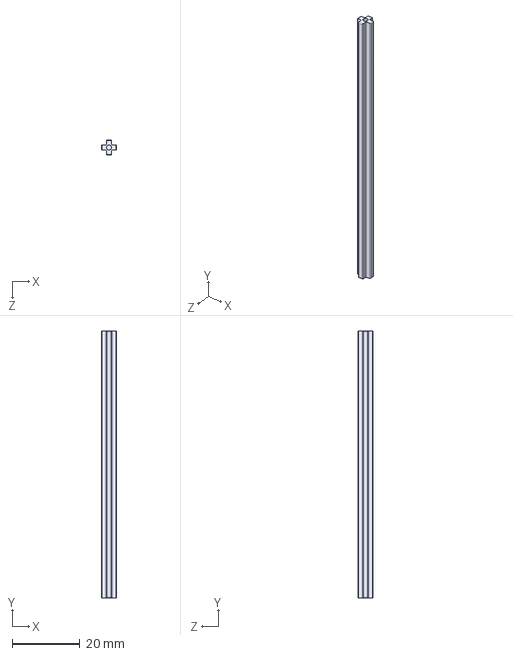
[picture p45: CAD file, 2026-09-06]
models/vtitan/step-files/base-de-sistema-de-transmision-corto.step
4.50 x 79.0 x 4.50 mm

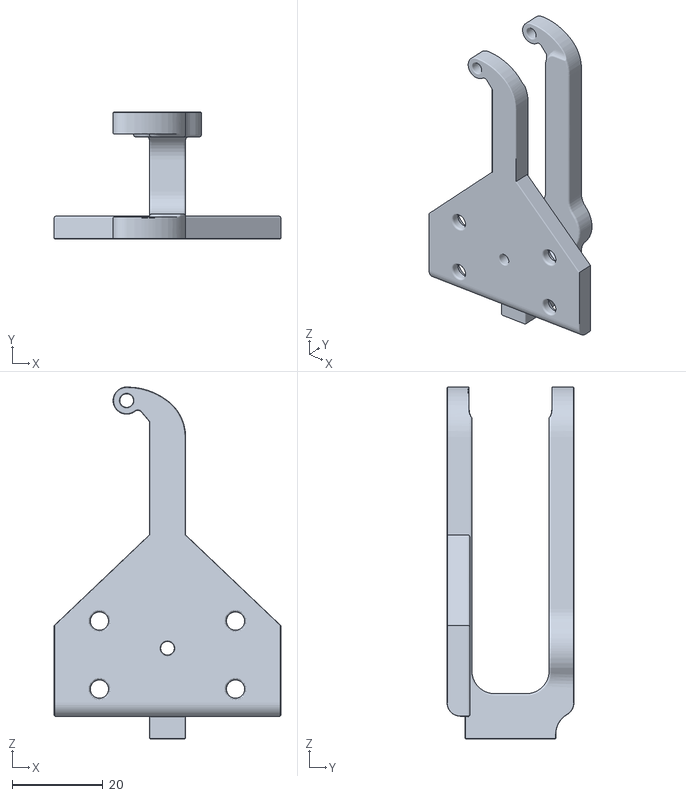
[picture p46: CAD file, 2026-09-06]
models/klevor/stl-files/mirror-brazo-de-direccion-1.stl
50.0 x 28.0 x 77.6

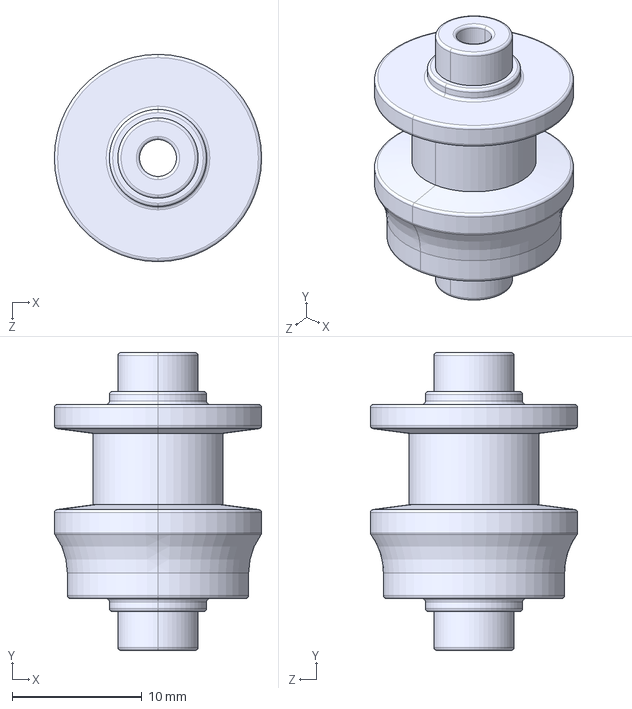
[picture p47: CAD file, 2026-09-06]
models/vtitan/step-files/rodillo-tensor-v1.step
16.0 x 23.0 x 16.0 mm

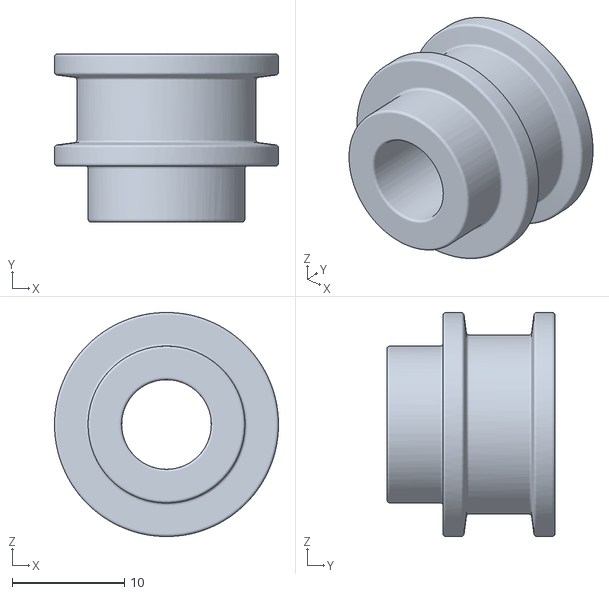
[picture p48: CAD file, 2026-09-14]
models/vtitan/stl-files/rodillo-tensor-v2.stl
20.0 x 15.0 x 20.0

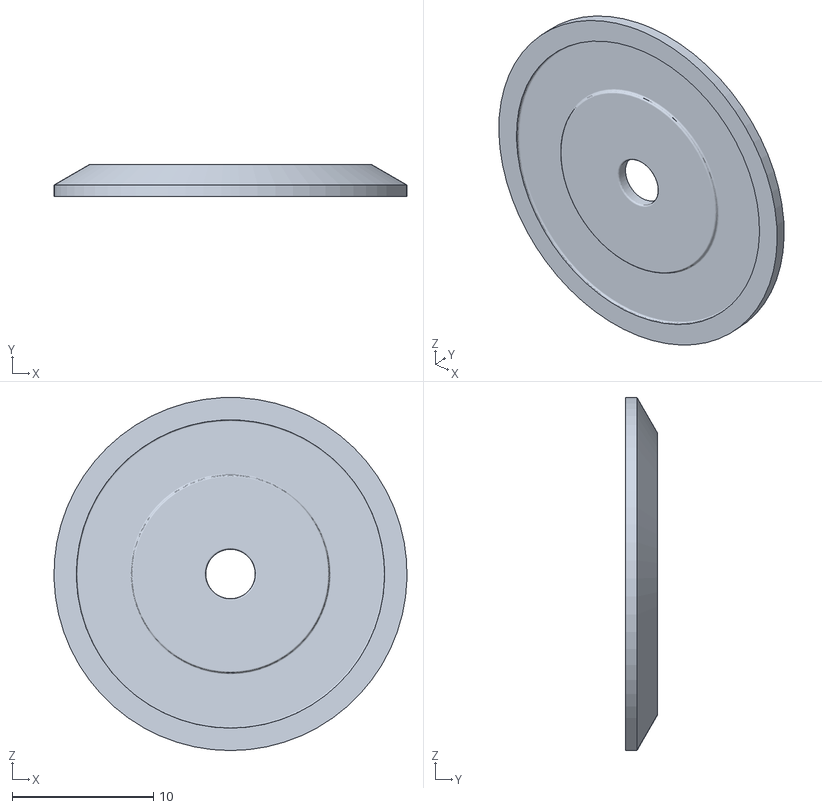
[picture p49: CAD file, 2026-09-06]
models/klevor/stl-files/arandela-de-fijacion-axial-discos-de-direccion.stl
25.0 x 2.25 x 25.0

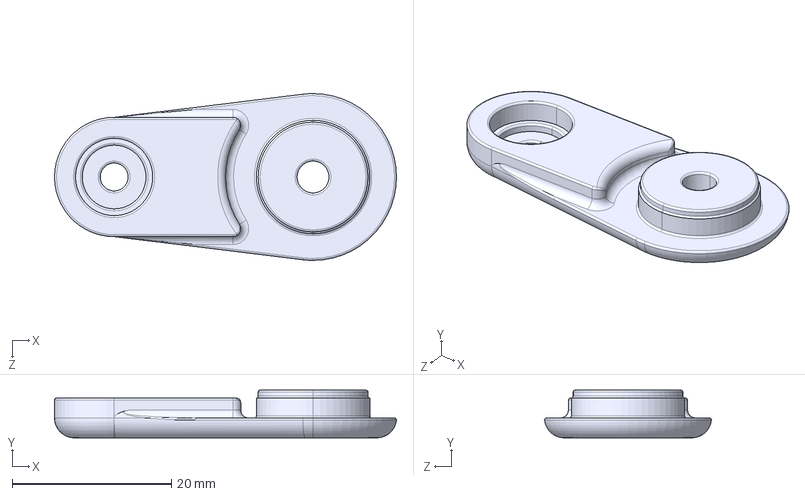
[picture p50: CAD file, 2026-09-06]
models/vtitan/step-files/brazo-de-tensor-v2.step
43.0 x 6.00 x 21.0 mm

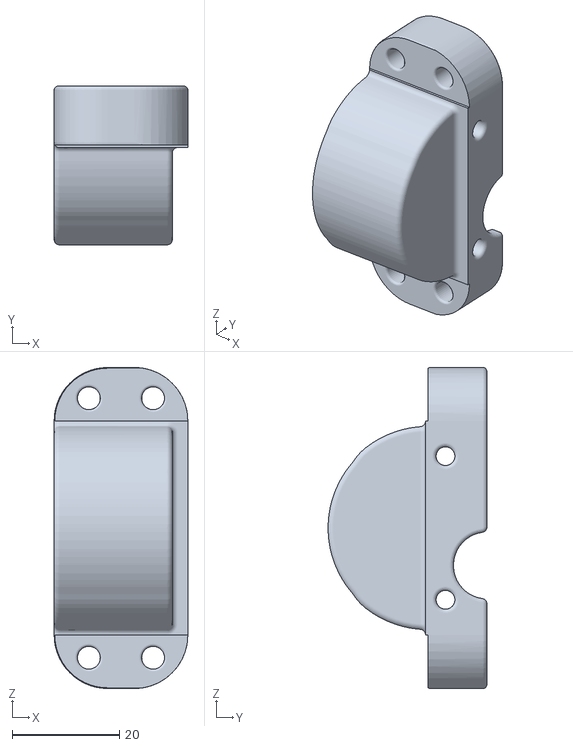
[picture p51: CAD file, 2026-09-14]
models/vtitan/stl-files/suplemento-de-bancada-motor-pequeno.stl
25.0 x 29.7 x 60.0

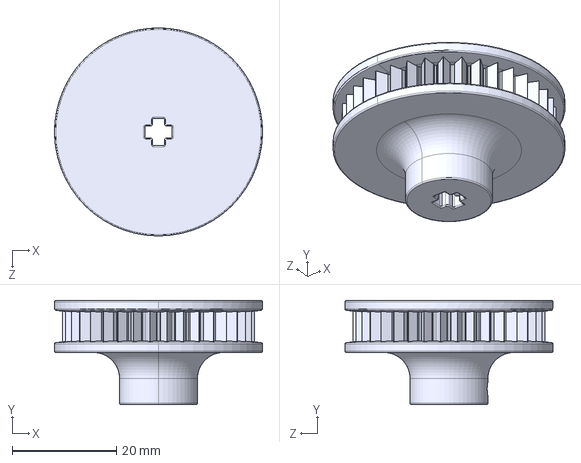
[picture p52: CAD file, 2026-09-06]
models/vtitan/step-files/pinon-33-dientes-correa-dentada.step
40.0 x 20.0 x 40.0 mm

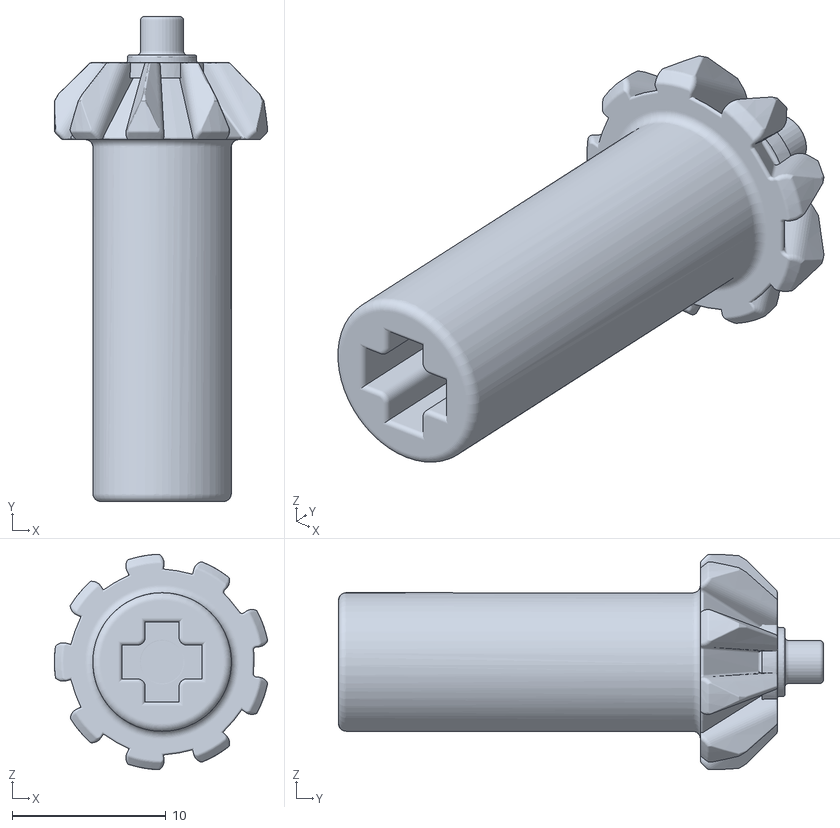
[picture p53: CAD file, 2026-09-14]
models/vtitan/stl-files/pinon-90-cruceta-10-dientes-con-eje.stl
13.9 x 31.5 x 14.0

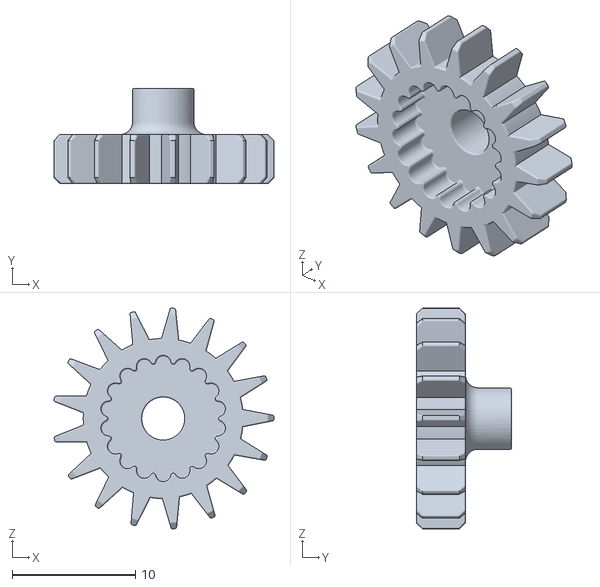
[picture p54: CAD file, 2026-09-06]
models/klevor/stl-files/pinon-de-17-dientes-direccion-inversion.stl
17.9 x 7.75 x 17.9

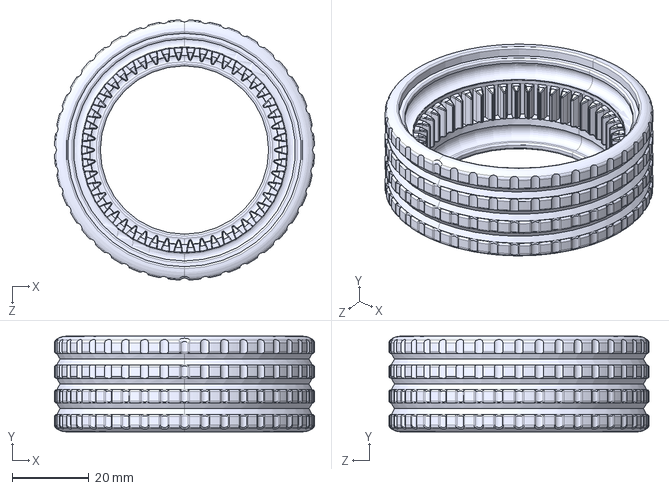
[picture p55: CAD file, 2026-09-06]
models/vtitan/step-files/rueda-dentada.step
68.0 x 25.0 x 68.0 mm

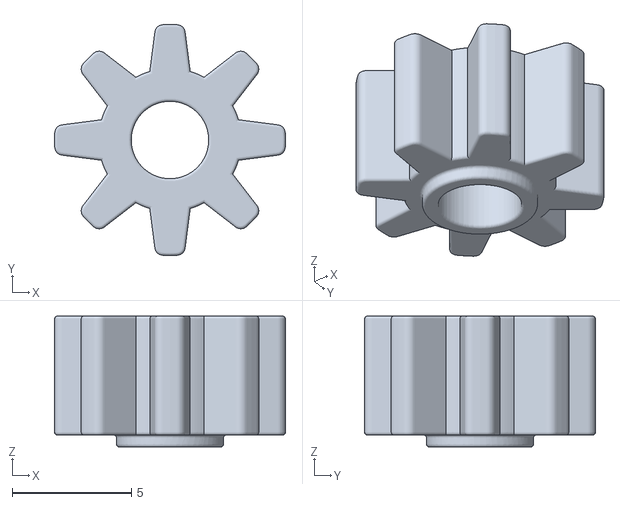
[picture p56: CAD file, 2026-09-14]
models/vtitan/stl-files/pinon-8-dientes-direccion.stl
9.70 x 9.70 x 5.50

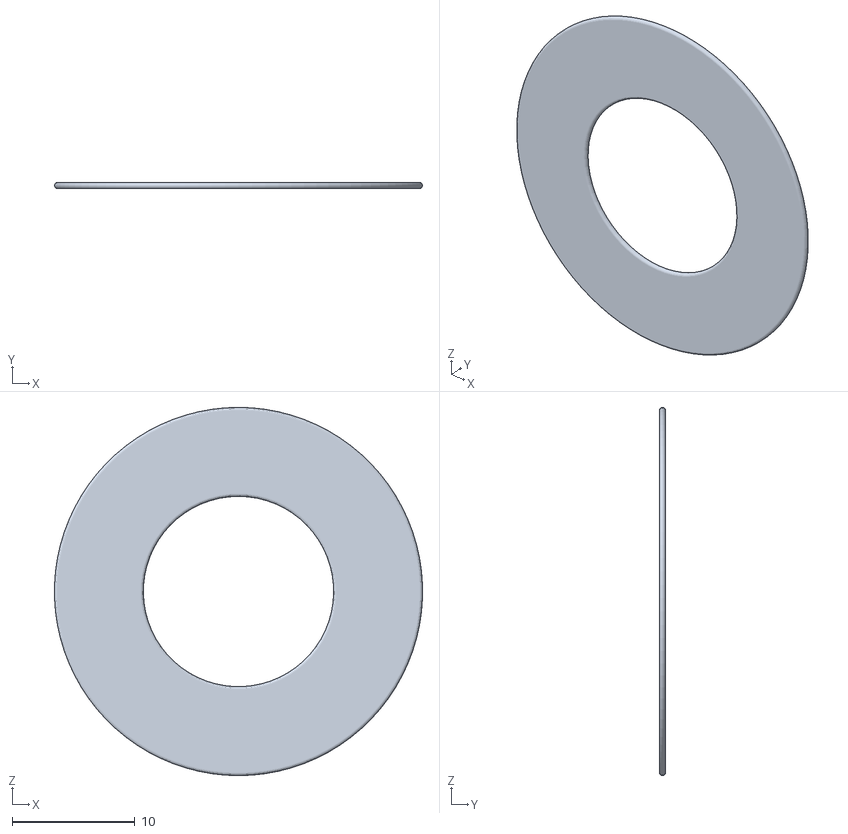
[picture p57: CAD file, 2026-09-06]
models/klevor/stl-files/aro-30-20-0.5.stl
30.0 x 0.5 x 30.0

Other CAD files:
models/klevor/stl-files/brazo-de-direccion-1.stl
models/vtitan/stl-files/pinon-20-dientes-direccion-v2.stl
models/klevor/stl-files/pinon-90-cruceta.stl
models/vtitan/step-files/rolinera-6.35-9.525-3.175.step
models/klevor/stl-files/aro-de-fijacion-axial-caucho.stl
models/klevor/stl-files/bancada-central.stl
models/klevor/stl-files/bancada-de-transmision.stl
models/klevor/stl-files/base-motor-jgb-37-12v-dc.stl
models/klevor/stl-files/base-sensores-hall.stl
models/klevor/stl-files/chasis-inferior.stl
models/klevor/stl-files/disco-base-de-sistema-direccion.stl
models/klevor/stl-files/disco-central-de-direccion-3-invertido.stl
models/klevor/stl-files/disco-central-de-direccion-3.stl
models/klevor/stl-files/disco-central-de-direccion-grande.stl
models/klevor/stl-files/disco-central-de-direccion-intermedio.stl
models/klevor/stl-files/flanche-soporte-motor-dc-200.stl
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

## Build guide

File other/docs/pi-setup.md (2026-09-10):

# Raspberry Pi setup & provisioning

Canonical record of how the three Raspberry Pis are configured: the developer /
build machine (set up by hand) and the two robot nodes (provisioned by
Ansible, `deploy/ansible/` - via `task rpi:provision:pi5` / `task rpi:provision:zero`
- which replaced the old `scripts/setup_pi_*.sh` scp+ssh scripts, removed
2026-07-30). Also lists what provisioning **doesn't** cover, so nothing is
silently missing.

## Machines & roles

| Machine | Role | Provisioned by |
|---|---|---|
| **Dev / build Pi 5** (`ralvarezdev-raspberrypi`, user `ralvarezdev`) | Developer workstation: edits, builds, flashes, remote access | by hand (documented below) |
| **Robot Pi 5** (user `ralvarezdev`) | State machine, vision (Hailo), IMU, LiDAR, telemetry bridge | `deploy/ansible/roles/pi5` (`task rpi:provision:pi5`) |
| **Robot Pi Zero 2W** (user `ralvarezdev`) | Motors (servo + DC encoder), button, OLED | `deploy/ansible/roles/pi_zero` (`task rpi:provision:zero`) |

All three run **Raspberry Pi OS Lite (64-bit)** / Debian 13 (trixie), arm64.
64-bit is mandatory - pixi/conda-forge has no 32-bit ARM packages.

---

## Dev / build Pi 5 - installed tooling

Set up manually; recorded here so it's reproducible. (AI coding assistants are
intentionally not listed.)

**Base:** Raspberry Pi 5 Model B, Debian 13 trixie arm64, 2 GB zram swap, user in
groups `gpio i2c spi dialout render video`.

**Source control & GitHub:**
- `git` with **GPG commit signing** (`user.signingkey=D2661E4AD09ED1CD`,
  `commit.gpgsign=true`); GPG key `rsa4096/D2661E4AD09ED1CD`
- `gh` (GitHub CLI) authenticated; configured as git credential helper
- `gpg` (gnupg)

**Remote access:**
- `cloudflared` - installed, `cloudflared.service` enabled, tunnel configured in
  `/etc/cloudflared/` (`config.yml` + tunnel credentials JSON)
- **WireGuard VPN** (`utun420`, `100.64.0.0/10` CGNAT range - Tailscale)

**Build / language toolchains:**
- `pixi` (per-user) - drives the ROS2 robot environment
- `task` (go-task) - runs the repo Taskfiles
- `ansible` + `community.general` collection - provisions the two robot Pis
  (`task rpi:ansible:setup` installs both; see `deploy/ansible/README.md`)
- Go (`/usr/local/go`), Node (bundled by the Zed editor)

**AI accelerator (Hailo AI HAT+):** full stack via apt - `hailo-all 5.1.1`
(`hailort 4.23.0`, `hailo-tappas-core`, `hailort-pcie-driver`,
`python3-hailort`, `python3-hailo-tappas`, `rpicam-apps-hailo-postprocess`);
`hailort.service` enabled.

**Robot stack:** repo checked out as per-branch git **worktrees** under
`~/vtitan*` (master, platform, docs, hailo, hugo-docs, auto-annotator);
robot pixi env and `ros2_ws` built.

> Interfaces (i2c/spi/serial) are **disabled** on this box - it builds and
> flashes, it isn't wired to sensors. The robot nodes enable them.

---

## Robot nodes - two-phase provisioning

### Phase 1 - Raspberry Pi Imager (Windows)

Writes the OS and first-contact config. In OS customization: hostname, enable
SSH + public key, username (any name - the scripts derive it from
`$SUDO_USER`), password, WiFi (SSID/password/country), locale. See
`scripts/README.md`.

### Phase 2 - Ansible (run from the dev Pi 5, over SSH)

`task rpi:provision:pi5 PI5_IP=x.x.x.x` / `task rpi:provision:zero` - see
`deploy/ansible/README.md` for the role layout. Idempotent (`task rpi:ansible:check`
dry-runs with `--check --diff`), ported from and matching `scripts/setup_pi_*.sh`
(kept as a manual fallback, see `scripts/README.md`):

Both roles (`common` + board role): verify GitHub auth up front (`gh`, private
repo) → apt full-upgrade → hardware groups → deps → clone repo via `gh` →
pixi env + `build-ws` → install/enable systemd service(s) + udev rules →
reboot only if boot config actually changed.

**`pi_zero` role additionally:** config.txt overlays (`dwc2`, `pwm-2chan`,
`i2c`, `uart`), `cmdline.txt` `modules-load=dwc2,g_ether` + fixed gadget MACs,
NM-only `usb0` static profile **192.168.250.1/24**, swap bump for the build,
Pi 5 WiFi 2.4GHz band lock for first-contact reachability (released even on
failure).

**`pi5` role additionally:** raspi-config interfaces (i2c/spi/serial/camera),
Hailo runtime (`apt install hailo-all`), NM `usb0` host IP
**192.168.250.2/24**, LiDAR driver fetch + `vtitan-lidar.service`.

### Networking

Pi Zero ↔ Pi 5 USB-Ethernet gadget on **192.168.250.0/24** (Zero `.1` gadget,
Pi 5 `.2` host), **NetworkManager-only** - no netplan, no manual `ip` service, no
ICS switcher. WiFi (separate subnet) carries internet + first-contact SSH.
(Migrated off `10.250.250.0/24` - a VPN was intercepting all `10.0.0.0/8`
traffic and silently blackholing the direct link.)

### Getting internet on the road (away from the home network)

Three ways to *reach* the boards from Windows, only one of which gives the
boards themselves internet:

| Link | SSH alias | Subnet | Gives the Pi internet? |
|---|---|---|---|
| Home WiFi | `rpi-5-local`, `rpi-zero-local` | home router's LAN | Yes, if that WiFi has internet |
| Direct cable/USB-gadget | `rpi-5-direct`, `rpi-zero-direct` | `192.168.251.0/24` (Windows↔Pi5), `192.168.250.0/24` (Pi5↔Zero) | **No** - private point-to-point link only |
| Cloudflare Tunnel | `rpi-5-remote` | over the internet | N/A - this is *outbound from* the Pi, so it only works once the Pi already has internet via its own WiFi |

The direct links exist so you can always reach a board even with **no WiFi at
all** - that's also what makes them useful for bootstrapping WiFi at a new
location:

1. Plug the Ethernet cable Windows↔Pi 5 (`task windows:ethernet:setup-link` once,
   if `rpi-5-direct`'s static IP isn't already configured on this Windows
   machine).
2. Set the Pi 5's new WiFi credentials over that cable - works even though
   the Pi 5 has no WiFi connection yet:
   `task windows:set-wifi:pi5 SSID=name PASSWORD=pass`
3. Set the Pi Zero's new WiFi credentials the same way, hopping through the
   Pi 5 over the USB gadget link - works even though the Zero has no WiFi
   connection yet:
   `task windows:set-wifi:zero SSID=name PASSWORD=pass`
4. Both boards now have internet through the new network. `rpi-5-local` /
   `rpi-zero-local` will only resolve once you know each board's new IP on
   that network (DHCP-assigned, so it can differ from the home values baked
   into `Taskfile.yml`'s `RPI_LOCAL_IP` / `ZERO_WIFI_IP`) - check the new
   router's client list, or SSH in over the direct link and run
   `task rpi:iface-ip IFACE=wlan0`.

**Gotcha:** the Pi Zero is **2.4 GHz-only**. A phone hotspot or router that's
5 GHz-only (or dual-band under one SSID that prefers 5 GHz) will connect the
Pi 5 but leave the Zero unable to join - pick/force a 2.4 GHz network or SSID
for the Zero.

Remote SSH from anywhere (`rpi-5-remote`, via `cloudflared`) only reaches the
Pi 5, and only after step 2 has given it working internet; it doesn't help
bootstrap a brand-new location and doesn't reach the Zero directly (hop
through Pi 5 once connected, same as `rpi-zero-direct` does over the gadget
link).

---

## Coverage matrix - what provisioning does / doesn't cover

**✅ Covered (robot-runtime layer):** OS upgrade · hardware groups · interfaces ·
deps · private-repo clone via `gh` · pixi env + ROS2 build (+ LiDAR driver) ·
Hailo runtime (`hailo-all` via apt) · USB-gadget networking · systemd services
+ udev.

**➖ Intentionally omitted (dev/ops only - on the build box, not robot nodes):**
GPG commit signing · personal git identity · `task` (go-task) · cloudflared
tunnel · Tailscale/WireGuard.

**🔧 Not covered by anyone - Imager or manual:** hostname / username / WiFi /
SSH keys (Imager) · robot `.env` tuning (GPIO pins, `STEERING_BACKEND`,
`DRIVE_BACKEND`) · on-device steering calibration (`find_limits_interactive`,
see `src/python/KNOWN_ISSUES.md`) · physical sensor wiring.

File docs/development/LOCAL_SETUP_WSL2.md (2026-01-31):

# Local Development Setup - WSL2 + ROS2 Kilted Kaiju

## Hardware Requirements ✅
- **Your Setup:** 32GB RAM, RTX 4050, WSL2
- **Perfect for:** ROS2 + Gazebo simulation + ML training
- **GPU Support:** CUDA in WSL2 for YOLO training (if needed)

## Architecture Overview

```
┌─────────────────────────────────────────┐
│         Your Laptop (WSL2)              │
├─────────────────────────────────────────┤
│                                         │
│  ROS2 Humble Development Environment    │
│  ├─ Gazebo Simulation                   │
│  ├─ Vision Nodes (Python)               │
│  ├─ Control Nodes (Python)              │
│  ├─ Mock Sensors                        │
│  └─ RViz2 Visualization                 │
│                                         │
│  YOLO Training (optional)               │
│  ├─ PyTorch + CUDA                      │
│  ├─ YOLOv8 training                     │
│  └─ ONNX export                         │
│                                         │
└─────────────────────────────────────────┘
                 │
                 │ (Port when ready)
                 ↓
┌─────────────────────────────────────────┐
│      Raspberry Pi 5 (Competition)       │
├─────────────────────────────────────────┤
│  ROS2 Humble (same packages!)           │
│  ├─ Real sensors (Camera, LiDAR, IMU)   │
│  ├─ Hailo-8L acceleration               │
│  └─ micro-ROS bridge to Pico 2W         │
└─────────────────────────────────────────┘
```

---

## Phase 1: WSL2 + ROS2 Setup

### Step 1.1: Install ROS2 Humble

```bash
# Update WSL2
sudo apt update && sudo apt upgrade -y

# Add ROS2 repository
sudo apt install software-properties-common -y
sudo add-apt-repository universe
sudo apt update && sudo apt install curl -y

# Add ROS2 GPG key
sudo curl -sSL https://raw.githubusercontent.com/ros/rosdistro/master/ros.key -o /usr/share/keyrings/ros-archive-keyring.gpg

# Add repository to sources list
echo "deb [arch=$(dpkg --print-architecture) signed-by=/usr/share/keyrings/ros-archive-keyring.gpg] http://packages.ros.org/ros2/ubuntu $(. /etc/os-release && echo $UBUNTU_CODENAME) main" | sudo tee /etc/apt/sources.list.d/ros2.list > /dev/null

# Install ROS2 Humble Desktop (includes RViz2, Gazebo dependencies)
sudo apt update
sudo apt install ros-humble-desktop -y

# Install development tools
sudo apt install ros-dev-tools -y
sudo apt install python3-colcon-common-extensions -y
```

### Step 1.2: Configure Environment

```bash
# Add to ~/.bashrc
echo "source /opt/ros/humble/setup.bash" >> ~/.bashrc
echo "source ~/teamsteelbot_ws/install/setup.bash" >> ~/.bashrc  # Will create this workspace

# Reload
source ~/.bashrc
```

### Step 1.3: Create Workspace

```bash
# Create ROS2 workspace
mkdir -p ~/teamsteelbot_ws/src
cd ~/teamsteelbot_ws

# Build (empty for now)
colcon build
source install/setup.bash
```

---

## Phase 2: Install Simulation Tools

### Step 2.1: Gazebo Garden (for ROS2 Humble)

```bash
# Install Gazebo Garden
sudo apt install ros-humble-ros-gz -y

# Test installation
gz sim -v4
```

### Step 2.2: Install Additional ROS2 Packages

```bash
# Navigation and localization
sudo apt install ros-humble-navigation2 -y
sudo apt install ros-humble-nav2-bringup -y
sudo apt install ros-humble-robot-localization -y

# Vision
sudo apt install ros-humble-vision-msgs -y
sudo apt install ros-humble-image-transport -y
sudo apt install ros-humble-cv-bridge -y

# Visualization
sudo apt install ros-humble-rqt -y
sudo apt install ros-humble-plotjuggler-ros -y

# LiDAR (for simulation testing)
sudo apt install ros-humble-laser-geometry -y
```

### Step 2.3: Python Dependencies

```bash
# Computer vision
pip3 install opencv-python opencv-contrib-python
pip3 install numpy scipy

# YOLO (if using deep learning approach)
pip3 install ultralytics  # YOLOv8
pip3 install torch torchvision  # PyTorch (CUDA support if available)

# ROS Python tools
pip3 install transforms3d
```

---

## Phase 3: Project Structure Setup

### Step 3.1: Create Package Structure

```bash
cd ~/teamsteelbot_ws/src

# Create main packages
ros2 pkg create --build-type ament_python teamsteelbot_bringup
ros2 pkg create --build-type ament_python teamsteelbot_vision
ros2 pkg create --build-type ament_python teamsteelbot_control
ros2 pkg create --build-type ament_python teamsteelbot_sensors
ros2 pkg create --build-type ament_cmake teamsteelbot_msgs
ros2 pkg create --build-type ament_python teamsteelbot_simulation
```

### Step 3.2: Directory Structure

```
~/teamsteelbot_ws/
├── src/
│   ├── teamsteelbot_bringup/
│   │   ├── launch/
│   │   │   ├── simulation.launch.py       # Gazebo simulation
│   │   │   └── robot.launch.py            # Real robot (RPi5)
│   │   ├── config/
│   │   │   ├── simulation_params.yaml
│   │   │   └── robot_params.yaml
│   │   └── package.xml
│   │
│   ├── teamsteelbot_simulation/
│   │   ├── teamsteelbot_simulation/
│   │   │   ├── mock_camera_node.py        # Simulated camera
│   │   │   ├── mock_lidar_node.py         # Simulated LiDAR
│   │   │   └── track_generator.py         # Generate test tracks
│   │   ├── worlds/
│   │   │   └── race_track.sdf             # Gazebo world
│   │   ├── models/
│   │   │   └── racer_robot/               # URDF model
│   │   └── package.xml
│   │
│   ├── teamsteelbot_vision/
│   │   ├── teamsteelbot_vision/
│   │   │   ├── sign_detector_yolo.py      # YOLO-based detector
│   │   │   ├── sign_detector_classic.py   # Classical CV detector
│   │   │   └── detector_base.py           # Base class
│   │   └── package.xml
│   │
│   ├── teamsteelbot_control/
│   │   ├── teamsteelbot_control/
│   │   │   ├── decision_node.py           # Main decision logic
│   │   │   ├── state_machine.py           # FSM implementation
│   │   │   └── speed_controller.py        # Adaptive speed
│   │   └── package.xml
│   │
│   ├── teamsteelbot_sensors/
│   │   ├── teamsteelbot_sensors/
│   │   │   ├── sensor_fusion_node.py      # Mock IMU + encoders
│   │   │   └── distance_sensor_node.py    # Mock VL53L0X
│   │   └── package.xml
│   │
│   └── teamsteelbot_msgs/
│       ├── msg/
│       │   ├── SignDetection.msg
│       │   ├── ColorReading.msg
│       │   └── RobotState.msg
│       └── CMakeLists.txt
│
├── models/                                 # AI models
│   ├── yolov8n_signs.pt                   # PyTorch checkpoint
│   └── yolov8n_signs.onnx                 # ONNX export
│
├── datasets/                               # Training data
│   ├── images/
│   ├── labels/
│   └── synthetic/                          # Gazebo-generated
│
└── docs/
    └── development/
```

---

## Phase 4: Create Minimal Simulation

### Step 4.1: Simple Robot URDF

Create `~/teamsteelbot_ws/src/teamsteelbot_simulation/models/racer_robot/robot.urdf.xacro`:

```xml
<?xml version="1.0"?>
<robot xmlns:xacro="http://www.ros.org/wiki/xacro" name="racer_robot">

  <!-- Base Link -->
  <link name="base_link">
    <visual>
      <geometry>
        <box size="0.2 0.15 0.1"/>
      </geometry>
      <material name="blue">
        <color rgba="0 0 1 1"/>
      </material>
    </visual>
    <collision>
      <geometry>
        <box size="0.2 0.15 0.1"/>
      </geometry>
    </collision>
    <inertial>
      <mass value="1.0"/>
      <inertia ixx="0.01" ixy="0.0" ixz="0.0" iyy="0.01" iyz="0.0" izz="0.01"/>
    </inertial>
  </link>

  <!-- Camera Link -->
  <link name="camera_link">
    <visual>
      <geometry>
        <box size="0.02 0.04 0.02"/>
      </geometry>
      <material name="red">
        <color rgba="1 0 0 1"/>
      </material>
    </visual>
  </link>

  <joint name="camera_joint" type="fixed">
    <parent link="base_link"/>
    <child link="camera_link"/>
    <origin xyz="0.1 0 0.05" rpy="0 0 0"/>
  </joint>

  <!-- Add Gazebo plugins for camera, sensors -->
  <gazebo reference="camera_link">
    <sensor name="camera" type="camera">
      <update_rate>30</update_rate>
      <camera>
        <horizontal_fov>1.047</horizontal_fov>
        <image>
          <width>640</width>
          <height>480</height>
        </image>
      </camera>
      <plugin name="camera_controller" filename="libgazebo_ros_camera.so">
        <ros>
          <namespace>/racer</namespace>
          <remapping>~/image_raw:=camera/image_raw</remapping>
        </ros>
      </plugin>
    </sensor>
  </gazebo>

</robot>
```

### Step 4.2: Minimal Launch File

Create `~/teamsteelbot_ws/src/teamsteelbot_bringup/launch/simulation.launch.py`:

```python
from launch import LaunchDescription
from launch_ros.actions import Node
from launch.actions import ExecuteProcess

def generate_launch_description():
    return LaunchDescription([
        # Start Gazebo
        ExecuteProcess(
            cmd=['gz', 'sim', 'empty.sdf'],
            output='screen'
        ),

        # Camera publisher (mock for now)
        Node(
            package='teamsteelbot_simulation',
            executable='mock_camera_node',
            name='camera',
            output='screen'
        ),

        # RViz for visualization
        Node(
            package='rviz2',
            executable='rviz2',
            name='rviz2',
            output='screen'
        ),
    ])
```

---

## Phase 5: Development Workflow

### Daily Development Loop

```bash
# Terminal 1: Build workspace
cd ~/teamsteelbot_ws
colcon build --symlink-install  # Symlink allows live Python edits
source install/setup.bash

# Terminal 2: Launch simulation
ros2 launch teamsteelbot_bringup simulation.launch.py

# Terminal 3: Monitor topics
ros2 topic list
ros2 topic echo /camera/image_raw

# Terminal 4: Visualize with RViz2
rviz2
```

### Testing Individual Nodes

```bash
# Test vision node standalone
ros2 run teamsteelbot_vision sign_detector_classic

# Test decision node
ros2 run teamsteelbot_control decision_node

# Check node graph
rqt_graph
```

---

## Phase 6: GPU Setup (Optional - for YOLO Training)

### Enable CUDA in WSL2

```bash
# Check if NVIDIA driver is visible
nvidia-smi

# Install CUDA toolkit (if needed)
wget https://developer.download.nvidia.com/compute/cuda/repos/wsl-ubuntu/x86_64/cuda-wsl-ubuntu.pin
sudo mv cuda-wsl-ubuntu.pin /etc/apt/preferences.d/cuda-repository-pin-600
sudo apt-key adv --fetch-keys https://developer.download.nvidia.com/compute/cuda/repos/wsl-ubuntu/x86_64/3bf863cc.pub
sudo add-apt-repository "deb https://developer.download.nvidia.com/compute/cuda/repos/wsl-ubuntu/x86_64/ /"
sudo apt update
sudo apt install cuda-toolkit-12-3 -y

# Install cuDNN for PyTorch
# (Follow PyTorch installation guide for WSL2)
```

### Test PyTorch GPU

```python
import torch
print(f"CUDA available: {torch.cuda.is_available()}")
print(f"Device: {torch.cuda.get_device_name(0)}")
```

---

## Phase 7: Simulation-to-Real Transfer Checklist

When moving from laptop to RPi5:

### 7.1: Code Transfer
```bash
# On laptop: Export packages
cd ~/teamsteelbot_ws/src
tar -czf teamsteelbot_packages.tar.gz teamsteelbot_*

# Transfer to RPi5 (USB, scp, git, etc.)
scp teamsteelbot_packages.tar.gz pi@raspberrypi.local:~/
```

### 7.2: Hardware-Specific Changes

**Swap these files:**
- `launch/simulation.launch.py` → `launch/robot.launch.py`
- `mock_camera_node.py` → Real camera node (libcamera)
- `mock_lidar_node.py` → RPLiDAR driver
- `mock_sensors.py` → Real I2C sensors (IMU, VL53L0X, TCS34725)

**Keep these (no changes needed!):**
- Vision detection nodes
- Decision/control logic
- State machine
- Custom messages

### 7.3: Configuration Changes

**simulation_params.yaml** (Laptop):
```yaml
camera:
  fps: 60  # High for testing
  resolution: [640, 480]

use_gazebo: true
use_mock_sensors: true
```

**robot_params.yaml** (RPi5):
```yaml
camera:
  fps: 30  # Realistic for Pi Camera
  resolution: [640, 480]

use_gazebo: false
use_mock_sensors: false
hailo_acceleration: true
```

---

## Next Steps

### Immediate (Week 1):
1. ✅ Install ROS2 Humble on WSL2
2. ✅ Create workspace structure
3. ✅ Verify basic ROS2 commands work
4. ✅ Install Gazebo and test launch

### Short-term (Week 2-3):
1. Create minimal simulation world (track with colored signs)
2. Implement vision detection node (start with classical CV)
3. Implement basic state machine (follow line, detect signs)
4. Test in simulation

### Mid-term (Week 4-6):
1. Add YOLO detection (train on synthetic data from Gazebo)
2. Implement sensor fusion
3. Fine-tune control logic
4. Record ROS bags for analysis

### Long-term (Week 7+):
1. Port to RPi5
2. Integrate real sensors
3. Test on physical track
4. Iterate and optimize

---

## Troubleshooting

### Common WSL2 Issues

**GUI applications not showing:**
```bash
# Install WSLg (Windows 11) or VcXsrv (Windows 10)
# Set DISPLAY variable if needed
export DISPLAY=:0
```

**ROS2 daemon issues:**
```bash
ros2 daemon stop
ros2 daemon start
```

**Gazebo performance:**
```bash
# Reduce rendering quality in Gazebo GUI
# Or run headless: gz sim -s (server only)
```

---

## Resources

- **ROS2 Tutorials:** https://docs.ros.org/en/humble/Tutorials.html
- **Gazebo Tutorials:** https://gazebosim.org/docs
- **YOLOv8 Docs:** https://docs.ultralytics.com/
- **WSL2 GPU Guide:** https://learn.microsoft.com/en-us/windows/ai/directml/gpu-cuda-in-wsl

---

## Summary

**Your laptop is perfect for:**
- ✅ ROS2 development and testing
- ✅ Vision algorithm development
- ✅ Control logic testing
- ✅ YOLO training (with RTX 4050!)
- ✅ Simulation of full robot

**Transfer to RPi5 later for:**
- Real sensor integration
- Hailo acceleration
- micro-ROS bridge
- Physical testing

**Key Advantage:** Develop 80% of code on fast laptop, only need RPi5 for final integration!

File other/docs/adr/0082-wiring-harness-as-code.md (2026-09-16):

# 0082. The wiring harness is defined as code

- Status: accepted
- Date: 2026-09-15

## Context

A hand-drawn connection diagram cannot be diffed, so a pin change is not versioned
the way the rest of the robot is. The README had claimed a connection diagram
existed for a long time while the folder held only two superseded flowcharts.

## Options considered

- (a) Draw the harness by hand and export an image.
- (b) Define the harness as code (tscircuit) and commit the exports.

## Decision

(b). The harness is defined in `schemes/wiring/tscircuit/circuit.tsx` and built
with tscircuit, so a pin change is a versioned code change. The exported
`harness.schematic.svg` and `harness.schematic.png` are committed because they are
what the documentation reads and rebuilding them needs the full toolchain; the PNG
is kept as a universal fallback and is the only scheme not converted to WebP.
Regeneration is `npm install` then `npm run artifacts`.

A schematic that renders proves nothing about connectivity: connectivity is
verified through the readable netlist, which lists net membership rather than
drawn wires. Ground is one 26-pin net, drawn as a GND netlabel per pin rather than
26 pairwise traces.

## Consequences

- The harness is reviewable and versioned with the code.
- Four intentionally unconnected pins are documented, not errors.
- The readable netlist is the check, not the rendered image.

## History

- 4e6beed3 2026-09-03: complete and verify the tscircuit harness. Splitters and
  buck converters had unconnected IN/OUT pins, so the battery rails stopped dead
  while the schematic rendered and `tsci build` reported zero errors.
- b7290f10 2026-09-05: pin the last unknowns and make the exports reproducible;
  correct the jumper location (Pi Zero, not Pi 5).
- 081fc868 2026-09-05: lay the schematic out in three bands.
- 3fa9cbfc 2026-09-05: draw ground as a symbol per pin, not as 26 wires (73 to 47
  traces in the JSX; still 73 source traces).
- 912c96b2 2026-09-05: render on white.
- 5034699f 2026-09-05: centralize diagrams and commit the harness schematic.
- 3a73ff3a 2026-09-08: move `docs/schemes/` to the repo-root `schemes/`.
- 878b8485 2026-09-14: document the harness in `schemes/README.md`.

## Refuted

- The harness compiling or rendering as evidence of connectivity; the jumper on
  the Pi 5; the retired JGB37-520 motor.

## Cross-references

- 0076 owns the pins and H-bridge wiring; 0073 owns the jumper.

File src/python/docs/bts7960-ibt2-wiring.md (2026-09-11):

# BTS7960/IBT-2 Wiring: Independent RPWM/LPWM

`src/hardware/motors/bts7960/driver.py` wires genuinely independent PWM
signals into the IBT-2 module's `RPWM` and `LPWM` inputs -- matching every
documented reference wiring for this chip -- and holds `R_EN`/`L_EN`
permanently HIGH. Direction is selected entirely by which PWM channel
carries a nonzero duty; the other is held at 0.

## Two earlier revisions, both wrong, for different reasons

1. An external 2:1 demux (two AND gates or a 74HC157) synthesizing
   `RPWM`/`LPWM` from a direction bit, with both enables tied permanently
   high. That hardware was never built for this board -- `connect()`
   succeeded, duty writes succeeded, and the motor just never turned.
2. ONE shared PWM signal into both `RPWM`/`LPWM`, direction selected by
   toggling `R_EN`/`L_EN` instead. This assumed a disabled side's
   half-bridge ignores its own PWM input. It doesn't: per the chip's own
   truth table, `RPWM=LPWM=HIGH` is **Fast Brake** (motor terminals
   shorted) and `RPWM=LPWM=LOW` is **Coast**. Tying them together means the
   chip alternates between exactly those two *braking* states every PWM
   cycle, regardless of `R_EN`/`L_EN` -- never actual drive. The module was
   very likely fine the whole time; the wiring scheme itself could never
   have worked.

## Why independent channels need two PWM sources

BTS7960 exposes two independent PWM inputs (`RPWM`/`LPWM`, one per
direction, each gated by its own `R_EN`/`L_EN`, which the module needs held
HIGH regardless of anything direction-related). The Pi Zero 2 W's SoC has
exactly 2 hardware PWM engines, one already claimed by the steering servo
-- so genuinely independent `RPWM`/`LPWM` means one of them has to be
software PWM.

Forward (`RPWM`) gets the Pi's one free **hardware** PWM engine: it's the
overwhelmingly more frequent, performance-critical direction. Reverse
(`LPWM`) rides **software** PWM via `gpiozero` (the `lgpio` pin factory this
board uses): measured jitter is real but mild, and reverse is only ever
used for parking/recovery at low duty, tolerant of it in a way the steering
servo's absolute-position hold is not (see `servo/driver.py`'s docstring --
that's exactly why the servo stays on hardware PWM and never moves to
software PWM).

## Wiring

| Signal | Pi pin | Role |
|---|---|---|
| Servo PWM | GPIO12 (hw PWM0) | Unchanged from the L298N setup |
| `RPWM` (forward) | GPIO13 (hw PWM1) | Same channel the L298N's `ENA` used; hardware PWM |
| `LPWM` (reverse) | GPIO26 | Software PWM (`gpiozero`); repurposed from the abandoned demux `dir_select` wire |
| `R_EN` | GPIO6 | Held permanently HIGH -- gates protection, not direction |
| `L_EN` | GPIO5 | Held permanently HIGH -- gates protection, not direction |

Defaults live on `Bts7960PwmConfig` (`src/config/hardware/motors/bts7960.toml`)
-- override there or via `BTS7960_PWM_*` env vars if wired differently.

## Not wired: current-sense (`R_IS`/`L_IS`)

The IBT-2 module also exposes `R_IS`/`L_IS` -- analog voltages proportional
to each half-bridge's motor current, useful for stall/overcurrent detection.
These are **not connected or read** by this driver: they're analog, and the
Pi has no built-in ADC, so reading them needs an external ADC chip (e.g. an
MCP3008 over SPI, or ADS1115 over I2C) between the module and the Pi. No such
converter is on hand as of this writing -- if one is added later, it's a new
sensor input path (and a new ADC driver module), not a `Bts7960PwmConfig`
field.

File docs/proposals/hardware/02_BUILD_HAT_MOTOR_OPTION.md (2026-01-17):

# Build HAT + LEGO Technic Motor Option Analysis

**NEW OPTION: Raspberry Pi Build HAT + LEGO Technic Large Motor (88013)**

---

## 🎯 Overview

This document analyzes using the **Raspberry Pi Build HAT** with **LEGO Technic Large Motor (88013)** as an alternative to your current INJORA motor setup and the LEGO SPIKE Prime motor option from the motor comparison document.

**Key Advantage:** Much simpler integration than custom LEGO SPIKE adapter board!

---

## 🔧 Hardware Specifications

### Raspberry Pi Build HAT

**Connectivity:**
- Mounts directly on Raspberry Pi 40-pin GPIO header
- Compatible with all Raspberry Pi models with 40-pin header (including your Pi 5!)
- 4× LPF2 connectors for LEGO Powered Up motors/sensors
- Onboard RP2040 microcontroller handles low-level motor control

**Power:**
- Requires separate 8V ±10% DC power supply (2.1mm barrel jack, center positive)
- Can use 7.5V battery pack OR official Build HAT Power Supply
- Powers motors independently from Raspberry Pi

**Supported Devices:**
- All LEGO Technic devices from SPIKE Portfolio
- LEGO Mindstorms Robot Inventor devices
- All LEGO Powered Up (LPF2) compatible motors/sensors

**Software:**
- Official Python library: `buildhat`
- Easy installation: `pip install buildhat`
- Well-documented API
- Works alongside other Pi peripherals (camera, etc.)

**Cost:** ~$25-35

---

### LEGO Technic Large Motor (88013)

**Official Specifications** (from LEGO Education):

| Condition | Speed | Torque | Current |
|---|---|---|---|
| **No-Load** | 175 RPM ± 15% | 0 Ncm | 135 mA ± 15% |
| **Running Load** | 135 RPM ± 15% | 8 Ncm | 430 mA ± 15% |
| **Stall** | 0 RPM | 25 Ncm | 1400 mA ± 15% |

*All specs at 7.2V power supply*

**Encoder Specifications:**
- Resolution: 360 counts per revolution
- Accuracy: ≤ ±3 degrees
- Update Rate: 100 Hz
- Type: Absolute encoder (within one rotation)

**Features:**
- Integrated rotation sensor
- Absolute positioning for accurate speed/position control
- LEGO Technic mounting holes (easy integration)
- Includes connecting wire with LPF2 connector

**Cost:** ~$20-30

**Total System Cost:** ~$45-65 (Build HAT + Motor)

---

## 📊 Comparison with Other Options

### vs. Your Current INJORA 180 Motor

| Feature | INJORA 180 | Build HAT + LEGO 88013 |
|---|---|---|
| **Encoder** | ❌ None | ✅ 360 CPR, absolute |
| **Max Speed** | 20,500 RPM (no load) | 175 RPM (no load) |
| **Torque** | Unknown | 25 Ncm stall |
| **Position Control** | ❌ Time-based only | ✅ Absolute position |
| **Integration Effort** | ✅ Already done | ⚠️ Need Build HAT |
| **Cost** | $0 (have it) | $45-65 |
| **ROS2 Odometry** | ❌ No encoder | ✅ Perfect |
| **Mounting** | Custom | LEGO Technic |

**Note:** INJORA is MUCH faster but lacks encoder feedback!

---

### vs. LEGO SPIKE Prime Motor (from doc 06)

| Feature | SPIKE Prime (Custom) | Build HAT + 88013 |
|---|---|---|
| **Motor** | LEGO Large Angular Motor | LEGO 88013 (same specs!) |
| **Speed** | 175 RPM | 175 RPM |
| **Torque** | 25 Ncm | 25 Ncm |
| **Encoder** | 360 CPR | 360 CPR |
| **Integration** | ❌ Custom adapter board needed | ✅ Build HAT (plug & play) |
| **Wiring** | Complex (level shifters, H-bridge) | ✅ Simple (LPF2 cable) |
| **Software** | Custom driver on Pico 2W | ✅ Python library ready |
| **Cost** | $30-40 + adapter (~$10) = $40-50 | $45-65 |
| **Development Time** | High (design adapter PCB) | Low (ready to use) |

**Verdict:** Build HAT is MUCH easier to integrate!

---

### vs. INJORA + PMW3901 Optical Flow (Recommended in doc 06)

| Feature | INJORA + PMW3901 | Build HAT + 88013 |
|---|---|---|
| **Odometry Type** | Optical flow (ground) | Wheel encoder |
| **Slip Immunity** | ✅ Yes (optical) | ❌ Wheel slip possible |
| **Innovation Factor** | ⭐⭐⭐ High | ⭐⭐ Medium |
| **Surface Dependency** | ⚠️ Needs texture | ✅ Any surface |
| **Cost** | $30 (PMW3901) | $45-65 |
| **Motor Speed** | 20,500 RPM | 175 RPM |
| **Integration** | Moderate (SPI sensor) | Moderate (Build HAT) |
| **ROS2 Compatibility** | ✅ Works well | ✅ Works well |

**Trade-off:** Optical flow is more innovative and slip-immune, but Build HAT gives traditional encoder odometry.

---

## 🏗️ Integration with Your Setup

### Current Setup (Klevor)
- Raspberry Pi 5 (16GB)
- Raspberry Pi Pico 2 WH (motor controller)
- USB-CDC communication (Pico ↔ Pi)
- INJORA motor + ESC

### With Build HAT Integration

**Option A: Replace Pico 2W for Motors (Simplest)**
```
┌─────────────────────────────────────────┐
│ Raspberry Pi 5                          │
│ ┌─────────────────────────────────────┐ │
│ │ ROS2 Nodes (Python)                 │ │
│ │ - Vision (Camera Module 3)          │ │
│ │ - YOLO on AI HAT+                   │ │
│ │ - LiDAR (USB)                       │ │
│ │ - IMU (I2C)                         │ │
│ │ - Motor Control via Build HAT       │ │
│ └─────────────────────────────────────┘ │
│           │                              │
│           ├─ GPIO Header                 │
│           │                              │
│   ┌───────▼──────────┐                  │
│   │ Build HAT        │                  │
│   │ (RP2040 onboard) │                  │
│   └──────────────────┘                  │
│    │    │    │    │                     │
└────┼────┼────┼────┼─────────────────────┘
     │    │    │    │
   Port1 Port2 Port3 Port4
     │    │    │    │
  LEGO  LEGO Optional Optional
  Motor Servo Sensor  Sensor
  88013
```

**Advantages:**
- ✅ Simplifies architecture (one less microcontroller)
- ✅ Direct Python control from Pi 5
- ✅ No USB-CDC protocol needed
- ✅ Build HAT handles low-level motor control

**Trade-offs:**
- ⚠️ Can't reuse your INJORA motor (Build HAT only for LEGO)
- ⚠️ Your Pico 2W becomes unused (or repurpose for other tasks)

---

**Option B: Keep Pico 2W + Add Build HAT (Hybrid)**
```
┌─────────────────────────────────────────┐
│ Raspberry Pi 5                          │
│ - Build HAT for LEGO motors             │
│ - USB-CDC to Pico 2W for INJORA         │
└─────────────────────────────────────────┘
       │                    │
   Build HAT             USB-CDC
       │                    │
   LEGO 88013          Pico 2W
                           │
                      INJORA Motor
```

**Advantages:**
- ✅ Can use BOTH motor systems
- ✅ Flexibility for testing

**Disadvantages:**
- ❌ Overly complex
- ❌ Not recommended

---

## 💻 Software Integration (Option A - Recommended)

### Python Code Example with Build HAT

```python
#!/usr/bin/env python3
from buildhat import Motor
import time

# Initialize LEGO motor on port A
drive_motor = Motor('A')

# --- Basic Control ---

# Set speed (-100 to 100)
drive_motor.start(50)  # 50% speed forward
time.sleep(2)
drive_motor.stop()

# --- Position Control (Odometry!) ---

# Get current position (encoder counts)
current_pos = drive_motor.get_aposition()
print(f"Position: {current_pos} degrees")

# Move to absolute position
drive_motor.run_to_position(360, 50)  # Go to 360°, 50% speed
drive_motor.wait_for_arrival()

# Move relative distance
drive_motor.run_for_degrees(180, 50)  # Rotate 180° forward
drive_motor.wait_for_arrival()

# --- Speed Control with PID ---
drive_motor.set_default_speed(50)
drive_motor.start()

# --- Get telemetry ---
position = drive_motor.get_aposition()  # Absolute position
speed = drive_motor.get_speed()  # Current speed
```

### ROS2 Integration Example

```python
#!/usr/bin/env python3
import rclpy
from rclpy.node import Node
from geometry_msgs.msg import Twist
from nav_msgs.msg import Odometry
from buildhat import Motor
import math

class BuildHATMotorNode(Node):
    def __init__(self):
        super().__init__('buildhat_motor_node')

        # Initialize LEGO motors
        self.left_motor = Motor('A')
        self.right_motor = Motor('B')

        # ROS2 subscribers
        self.cmd_vel_sub = self.create_subscription(
            Twist,
            'cmd_vel',
            self.cmd_vel_callback,
            10
        )

        # ROS2 publishers
        self.odom_pub = self.create_publisher(Odometry, 'odom', 10)

        # Odometry timer (100 Hz - matches encoder update rate)
        self.create_timer(0.01, self.publish_odometry)

        # Robot parameters
        self.wheel_diameter = 0.056  # meters (56mm LEGO wheel)
        self.wheel_base = 0.15  # meters (distance between wheels)

        # Previous encoder positions
        self.prev_left_pos = 0
        self.prev_right_pos = 0

        self.get_logger().info('Build HAT Motor Node started')

    def cmd_vel_callback(self, msg):
        """Convert Twist to differential drive commands"""
        linear_vel = msg.linear.x  # m/s
        angular_vel = msg.angular.z  # rad/s

        # Differential drive kinematics
        left_vel = linear_vel - (angular_vel * self.wheel_base / 2)
        right_vel = linear_vel + (angular_vel * self.wheel_base / 2)

        # Convert m/s to motor speed (-100 to 100)
        left_speed = self.velocity_to_motor_speed(left_vel)
        right_speed = self.velocity_to_motor_speed(right_vel)

        # Command motors
        self.left_motor.start(left_speed)
        self.right_motor.start(right_speed)

    def velocity_to_motor_speed(self, vel):
        """Convert m/s to motor speed percentage"""
        # LEGO motor: 175 RPM @ 100% = 2.92 rev/s
        # Wheel circumference = π * diameter
        max_vel = 2.92 * math.pi * self.wheel_diameter  # ~0.51 m/s

        motor_speed = (vel / max_vel) * 100
        return max(-100, min(100, motor_speed))  # Clamp to [-100, 100]

    def publish_odometry(self):
        """Publish odometry from encoder data"""
        # Get current encoder positions (degrees)
        left_pos = self.left_motor.get_aposition()
        right_pos = self.right_motor.get_aposition()

        # Calculate change in position
        delta_left = math.radians(left_pos - self.prev_left_pos)
        delta_right = math.radians(right_pos - self.prev_right_pos)

        # Convert to linear distance
        left_dist = delta_left * (self.wheel_diameter / 2)
        right_dist = delta_right * (self.wheel_diameter / 2)

        # Calculate robot motion
        delta_dist = (left_dist + right_dist) / 2
        delta_theta = (right_dist - left_dist) / self.wheel_base

        # Create odometry message
        odom = Odometry()
        odom.header.stamp = self.get_clock().now().to_msg()
        odom.header.frame_id = 'odom'
        odom.child_frame_id = 'base_link'

        # Velocity (distance / dt)
        odom.twist.twist.linear.x = delta_dist / 0.01
        odom.twist.twist.angular.z = delta_theta / 0.01

        self.odom_pub.publish(odom)

        # Update previous positions
        self.prev_left_pos = left_pos
        self.prev_right_pos = right_pos

def main(args=None):
    rclpy.init(args=args)
    node = BuildHATMotorNode()
    rclpy.spin(node)
    node.destroy_node()
    rclpy.shutdown()

if __name__ == '__main__':
    main()
```

---

## ⚡ Power Considerations

### Power Requirements

**Build HAT:**
- Input: 8V ±10% DC (7.2V - 8.8V)
- Recommended: 7.5V battery pack (6× AA or 2S LiPo)
- Current: Depends on motors (up to 1.4A per motor at stall)
- Max total: ~5-6A (4 motors stalled)

**Your Current Battery:**
- URGENEX 7.4V Battery (3000 mAh, 2S LiPo)
- ✅ **PERFECT for Build HAT!** (7.4V is within 8V ±10% range)

**System Power Architecture:**

```
┌─────────────────────┐
│ Shargeek Storm 2    │ 25600 mAh, 100W
│ (Main battery)      │
└──────┬──────────────┘
       │
       ├─ USB-C → Raspberry Pi 5 (5V, 5A)
       │          ├─ Camera Module 3
       │          ├─ AI HAT+ 26 TOPS
       │          ├─ Build HAT (via GPIO)
       │          │
       │          └─ USB peripherals
       │              ├─ RPLiDAR C1
       │              └─ Other sensors
       │
       └─ (Optional) Can charge URGENEX battery

┌─────────────────────┐
│ URGENEX 7.4V        │ 3000 mAh, 2S LiPo
│ (Motor power)       │
└──────┬──────────────┘
       │
       └─ Build HAT Power Input (2.1mm barrel jack)
          └─ LEGO Motors (via LPF2 ports)
```

**Advantages:**
- ✅ Can reuse your URGENEX 7.4V battery for Build HAT!
- ✅ Clean power separation (logic vs motors)
- ✅ No additional battery needed

---

## 🎯 Recommendation for Your Setup

### For Proposal 4 (ROS2 Edge Racer)

**Choose Build HAT + LEGO 88013 if:**
- ✅ You want the **easiest integration** with encoders
- ✅ You want **professional, tested hardware** (LEGO Education)
- ✅ You prioritize **development speed** (Python library ready)
- ✅ You can afford **$45-65** for the combo
- ✅ You don't mind **slower max speed** (175 RPM vs 20,500 RPM)
- ✅ You want to **simplify** your setup (no Pico 2W needed)

**Choose INJORA + PMW3901 Optical Flow if:**
- ✅ You want **maximum innovation** (unique approach)
- ✅ You want **slip-immune odometry**
- ✅ You need **high speed** (20,500 RPM)
- ✅ You want to **save money** ($30 vs $45-65)
- ✅ You're OK with **more integration work** (SPI sensor + calibration)
- ✅ You want to **reuse existing motor**

**Choose Keep INJORA Only if:**
- ✅ You want **zero new cost**
- ✅ You accept **IMU/LiDAR-only odometry**
- ✅ You need **high speed** capability

---

## 🏆 Final Verdict

### Build HAT + LEGO 88013: **★★★★☆ (4/5 stars)**

**Pros:**
- ✅ Easiest encoder integration (no custom PCB!)
- ✅ Professional hardware (LEGO Education standard)
- ✅ Official Python library (well-documented)
- ✅ Perfect for ROS2 Nav2 (encoder odometry)
- ✅ Can reuse URGENEX 7.4V battery
- ✅ Absolute encoder (±3° accuracy)
- ✅ LEGO mounting (easy mechanical integration)
- ✅ Simplifies architecture (no Pico 2W needed)

**Cons:**
- ❌ More expensive than optical flow ($45-65 vs $30)
- ❌ Much slower than INJORA (175 RPM vs 20,500 RPM)
- ❌ Can't reuse existing INJORA motor
- ❌ Less innovative than optical flow approach
- ⚠️ Your Pico 2W becomes unused (unless repurposed)

**Best Use Case:**
- **Proposal 4 (ROS2 Edge Racer)** - if you prioritize development speed and proven hardware
- Great for beginners with LEGO integration
- Perfect if WRO track doesn't require high speed

---

## 🤔 Speed Consideration: Is 175 RPM Enough?

**CRITICAL QUESTION:** Is LEGO motor too slow for WRO?

**LEGO 88013 with typical wheel:**
- Motor: 175 RPM no-load, 135 RPM loaded
- Wheel: 56mm diameter LEGO wheel
- Speed calculation:
  ```
  Circumference = π × 0.056m = 0.176m
  Speed @ 135 RPM = 135 × 0.176m = 23.7 m/min = 0.40 m/s
  Speed @ 175 RPM (no-load) = 175 × 0.176m = 30.8 m/min = 0.51 m/s
  ```

**INJORA 180 with gearing:**
- Motor: 20,500 RPM no-load
- Gear ratio: 48:1
- Output: 427 RPM
- With 56mm wheel: 7.5 m/min = **1.25 m/s** (3× faster!)

**For WRO Racing:**
- ⚠️ LEGO motor (0.4 m/s) might be **too slow** for competitive times
- ✅ INJORA (1.25 m/s) is **much better for racing**

**Recommendation:**
- If WRO requires **speed**: Stick with INJORA + PMW3901 optical flow
- If WRO prioritizes **precision**: Build HAT + LEGO 88013 works

---

## 📋 Updated Cost Summary

| Option | Hardware Cost | Integration Effort | Speed | Encoder | Innovation |
|---|---|---|---|---|---|
| **Keep INJORA** | $0 | ✅ Done | ⭐⭐⭐ | ❌ | ⭐ |
| **INJORA + PMW3901** | $30 | Medium | ⭐⭐⭐ | ✅ Optical | ⭐⭐⭐ |
| **Build HAT + 88013** | $45-65 | Medium | ⭐ | ✅ Wheel | ⭐⭐ |
| **LEGO SPIKE (custom)** | $40-50 | High | ⭐ | ✅ Wheel | ⭐⭐ |

---

## 🚀 Implementation Timeline

### If Choosing Build HAT + LEGO 88013:

**Week 1:**
- [ ] Order Raspberry Pi Build HAT (~$25-35)
- [ ] Order LEGO Technic Large Motor 88013 (~$20-30)
- [ ] Optional: Order LEGO wheels/mounting parts
- [ ] Plan mechanical integration (LEGO chassis?)

**Week 2:**
- [ ] Install Build HAT on Pi 5
- [ ] Connect URGENEX 7.4V battery to Build HAT power
- [ ] Install Python library: `pip install buildhat`
- [ ] Test motor control (basic speed/position)

**Week 3:**
- [ ] Implement ROS2 motor node (cmd_vel subscriber)
- [ ] Implement ROS2 odometry publisher
- [ ] Test with Nav2 (basic movement commands)

**Week 4:**
- [ ] Integrate with YOLO vision system
- [ ] Test complete system
- [ ] Tune PID controllers

**Total:** 4 weeks to full integration

---

## 📚 Resources & Documentation

### Official Documentation:
- [Raspberry Pi Build HAT Documentation](https://www.raspberrypi.com/documentation/accessories/build-hat.html)
- [Build HAT Python Library](https://buildhat.readthedocs.io/en/latest/buildhat/index.html)
- [Build HAT GitHub Repository](https://github.com/RaspberryPiFoundation/python-build-hat)
- [LEGO Education SPIKE Prime Technical Specifications](https://le-www-live-s.legocdn.com/sc/media/files/support/spike-prime/techspecs_techniclargeangularmotor-1b79e2f4fbb292aaf40c97fec0c31fff.pdf)

### Community Resources:
- [Meet the Raspberry Pi Build HAT (Raspberry Pi News)](https://www.raspberrypi.com/news/raspberry-pi-build-hat-lego-education/)
- [Raspberry Pi Build HAT Review (Tom's Hardware)](https://www.tomshardware.com/reviews/raspberry-pi-build-hat-review-combine-lego-with-pi)
- [PyBricks Motor Documentation](https://docs.pybricks.com/en/stable/pupdevices/motor.html)

### Purchase Links:
- [Raspberry Pi Build HAT - Official Store](https://www.raspberrypi.com/products/build-hat/)
- [Adafruit Build HAT](https://www.adafruit.com/product/5287)
- [LEGO Technic Large Motor 88013](https://www.lego.com/en-us/product/technic-large-motor-88013)

---

## ✅ Summary

**Build HAT + LEGO 88013 is EXCELLENT if:**
- Development speed > Cost savings
- Precision > Raw speed
- Proven hardware > Innovation points
- You want simplest encoder integration

**Stick with INJORA + PMW3901 if:**
- Speed is critical for WRO
- Budget is tight ($30 vs $45-65)
- You want innovation points
- Slip-immune odometry matters

**My recommendation:**
1. **First choice:** INJORA + PMW3901 (better speed, innovation, cost)
2. **Second choice:** Build HAT + LEGO 88013 (easier integration, if speed OK)

**Test this:** Check WRO track dimensions and calculate required speed. If 0.4 m/s is sufficient, Build HAT is great. If you need 1+ m/s, stick with INJORA.

---

**Last updated:** 2026-01-16

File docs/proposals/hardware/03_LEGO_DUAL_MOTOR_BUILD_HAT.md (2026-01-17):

# Dual LEGO Motor Setup with Build HAT

**Using Your Bugatti Bolide Technic Parts + Build HAT + 2 LEGO Motors**

---

## 🎯 Your Situation

**What You Have:**
- ✅ LEGO Technic Bugatti Bolide #42151 (905 parts: gears, beams, axles, connectors)
- ✅ Raspberry Pi 5 (16GB)
- ✅ AI HAT+ 26 TOPS
- ✅ All sensors (Camera, LiDAR, IMU)
- ✅ INJORA 180 Motor + Servo (current setup)

**What You're Considering:**
- Buy 2× LEGO Technic Large Motors (88013)
- Buy 1× Raspberry Pi Build HAT
- Use LEGO for BOTH drive and steering
- Build chassis from Bugatti Bolide parts

---

## 🔧 Key Finding: LEGO Motors CAN Do Steering!

**Modern LEGO Powered Up motors have built-in encoders and can do position control!**

From research:
> "As a result of the L and XL motors being able to calibrate to become steering motors, there is no dedicated servo motor, as there is no need for one in the newer Powered Up and Control+ systems."

**This means:**
- ✅ LEGO Large/Medium motors CAN control steering (with encoders!)
- ✅ No need for separate servo motor
- ✅ All-LEGO solution is viable!

---

## 🚗 Two Steering Approaches

### Option A: Differential Steering (Tank/Skid Steering) ⭐ **RECOMMENDED**

**Setup:**
- 2× LEGO Large Motors (88013)
- Left motor drives left wheel(s)
- Right motor drives right wheel(s)
- Steering by running motors at different speeds

**How It Works:**
```
Turn Left:  Left motor slow, Right motor fast
Turn Right: Left motor fast, Right motor slow
Forward:    Both motors same speed forward
Backward:   Both motors same speed backward
Spin:       Left forward, Right backward (or vice versa)
```

**Advantages:**
- ✅ **Simplest setup** (only 2 motors needed!)
- ✅ **No steering mechanism** (no Ackermann linkage)
- ✅ **Zero turning radius** (can spin in place)
- ✅ **Perfect for WRO** (tight spaces, precise positioning)
- ✅ **Easier to build** with LEGO parts
- ✅ **More reliable** (fewer moving parts)
- ✅ **Cheaper** (2 motors vs 3)

**Disadvantages:**
- ⚠️ **Wheel slip** when turning (skids sideways)
- ⚠️ **Not car-like** (but WRO doesn't require car steering)
- ⚠️ **Depends on friction** (works best on rubber mats)

**Cost:**
- 2× LEGO Large Motor 88013: $40-60
- 1× Build HAT: $25-35
- **Total: $65-95**

**ROS2 Integration:**
```python
# Differential drive is BUILT-IN to ROS2!
from buildhat import Motor

left_motor = Motor('A')
right_motor = Motor('B')

def cmd_vel_callback(msg):
    """ROS2 Twist message → Differential drive"""
    linear = msg.linear.x   # Forward/backward speed
    angular = msg.angular.z # Turning rate

    # Differential drive equations
    left_speed = linear - angular * wheel_base / 2
    right_speed = linear + angular * wheel_base / 2

    left_motor.start(left_speed * 100)
    right_motor.start(right_speed * 100)
```

**ROS2 Support:**
- ✅ `diff_drive_controller` package (standard!)
- ✅ Nav2 fully supports differential drive
- ✅ Most tutorials use differential drive
- ✅ Easiest to tune

---

### Option B: Ackermann Steering (Car-Like Steering)

**Setup:**
- 1× LEGO Large Motor (88013) for drive (rear wheels)
- 1× LEGO Medium Motor (45603) for steering (front wheels)
- Ackermann linkage (LEGO gears/beams)

**How It Works:**
```
Drive motor:    Powers rear wheels
Steering motor: Turns front wheels via Ackermann linkage
                (like a real car)
```

**Advantages:**
- ✅ **Car-like steering** (more realistic)
- ✅ **Less wheel slip** (front wheels pivot)
- ✅ **Works on any surface** (less friction dependent)

**Disadvantages:**
- ❌ **More complex** (need Ackermann linkage)
- ❌ **Harder to build** (steering geometry critical)
- ❌ **Needs 3 motors** (2 drive + 1 steer, or 1 drive + 1 steer)
- ❌ **Larger turning radius** (can't spin in place)
- ❌ **More tuning** needed (steering calibration)
- ⚠️ **Overkill for WRO** (differential is sufficient)

**Cost:**
- 1× LEGO Large Motor 88013: $20-30 (drive)
- 1× LEGO Medium Motor 45603: $15-25 (steering)
- 1× Build HAT: $25-35
- **Total: $60-90**

**ROS2 Integration:**
```python
# Need Ackermann controller
from buildhat import Motor

drive_motor = Motor('A')
steer_motor = Motor('B')

def cmd_vel_callback(msg):
    """ROS2 Twist → Ackermann steering"""
    linear = msg.linear.x
    angular = msg.angular.z

    # Calculate steering angle from angular velocity
    steering_angle = atan(angular * wheelbase / linear)

    # Position control for steering
    steer_motor.run_to_position(steering_angle * 180/pi, 50)

    # Speed control for drive
    drive_motor.start(linear * 100)
```

**ROS2 Support:**
- ⚠️ `ackermann_steering_controller` available
- ⚠️ More complex tuning
- ⚠️ Fewer tutorials
- ⚠️ Not necessary for WRO

---

## 📊 Comparison: Differential vs Ackermann

| Factor | Differential (2 motors) | Ackermann (2-3 motors) |
|---|---|---|
| **Motors Needed** | 2 (drive only) ⭐ | 2-3 (drive + steer) |
| **LEGO Build Complexity** | ⭐⭐⭐⭐⭐ Easy | ⭐⭐ Complex |
| **Turning Radius** | Zero (spin in place) ⭐ | Larger |
| **Wheel Slip** | More (skids) | Less |
| **ROS2 Support** | ⭐⭐⭐⭐⭐ Excellent | ⭐⭐⭐ Good |
| **WRO Suitability** | ⭐⭐⭐⭐⭐ Perfect | ⭐⭐⭐ Adequate |
| **Cost** | $65-95 | $60-90 (similar) |
| **Setup Time** | Fast | Slow |
| **Reliability** | ⭐⭐⭐⭐⭐ High | ⭐⭐⭐ Medium |

**Recommendation:** **Differential steering** for WRO!

---

## 🏆 Full System Options

### Option 1: Full LEGO System (Differential) ⭐⭐⭐⭐⭐ **BEST CHOICE**

**Hardware:**
- 2× LEGO Large Motor 88013 ($40-60)
- 1× Raspberry Pi Build HAT ($25-35)
- 1× TCS34725 color sensor ($8)
- Chassis from Bugatti Bolide parts (FREE!)
- **Total: $73-103**

**What You Get:**
- ✅ **All-LEGO solution** (proven, reliable)
- ✅ **Simplest setup** (differential steering)
- ✅ **Plug & play** (Build HAT Python library)
- ✅ **Perfect for WRO** (tight spaces, zero turning radius)
- ✅ **Encoder odometry** (360 CPR per motor)
- ✅ **ROS2 compatible** (diff_drive_controller)
- ✅ **No Pico 2W needed** (eliminates complexity)
- ✅ **Easy mechanical integration** (LEGO mounting)

**What You Lose:**
- ❌ Speed (0.4 m/s max vs 1.25 m/s with INJORA)
- ❌ Optical flow innovation (using wheel encoders instead)

**Speed Calculation:**
```
2 motors in differential drive:
- Each motor: 135 RPM loaded
- Wheel: 56mm diameter (typical LEGO)
- Speed: 135 RPM × π × 0.056m = 0.40 m/s per motor

With differential drive, max forward speed = 0.40 m/s
(Both motors forward at same speed)
```

**Is 0.4 m/s enough for WRO?**
- ⚠️ Slower than INJORA setup (1.25 m/s)
- ✅ BUT: Tight turns, zero turning radius compensates
- ✅ WRO tracks often prioritize precision over raw speed
- ✅ Can navigate tight spaces better than Ackermann

---

### Option 2: Hybrid - INJORA Drive + LEGO Steering

**Hardware:**
- Keep INJORA 180 motor for drive (via Pico 2W)
- 1× LEGO Medium Motor 45603 for steering ($15-25)
- 1× Raspberry Pi Build HAT ($25-35)
- 1× PMW3901 optical flow ($30)
- 1× TCS34725 color sensor ($8)
- **Total: $78-98**

**What You Get:**
- ✅ **Fast drive** (1.25 m/s with INJORA)
- ✅ **LEGO steering** (position control, no servo calibration)
- ✅ **Optical flow** innovation
- ✅ **Best of both worlds**

**What You Lose:**
- ⚠️ More complex (Pico 2W + Build HAT)
- ⚠️ Need Ackermann steering mechanism
- ⚠️ More wiring/integration work

---

### Option 3: Keep Current Setup (INJORA + Servo)

**Hardware:**
- Keep INJORA 180 motor + servo
- 1× PMW3901 optical flow ($30)
- 1× TCS34725 color sensor ($8)
- **Total: $38**

**What You Get:**
- ✅ **Cheapest** option
- ✅ **Fastest** (1.25 m/s)
- ✅ **Already working** (mechanical integration done)
- ✅ **Optical flow** innovation

**What You Lose:**
- ❌ No wheel encoder odometry
- ❌ Keep Pico 2W complexity

---

## 🎯 Recommendation Based on Your Requirements

### **Go with Option 1: Full LEGO Differential System!** ⭐

**Why:**

1. **✅ Configuration Flexibility (Your #1 Requirement!)**
   - Build HAT + ROS2 = JSON/YAML config
   - Differential drive = simplest ROS2 integration
   - Change mission logic in seconds
   - Perfect for surprise rules

2. **✅ Uses Your Bugatti Bolide Parts**
   - 905 LEGO Technic parts ready to use!
   - No need to design custom chassis
   - LEGO mounting = easy assembly/modification
   - Professional look

3. **✅ Simplest System**
   - Only 2 motors + Build HAT
   - No Pico 2W (eliminates complexity)
   - Proven LEGO Education hardware
   - Plug & play Python library

4. **✅ Perfect for WRO**
   - Zero turning radius (spin in place!)
   - Precise positioning
   - Reliable mechanical design
   - Most robots use differential drive

5. **✅ Best Encoder Odometry**
   - 2× encoders (one per motor)
   - Absolute position tracking
   - ROS2 diff_drive_controller built-in
   - Easy EKF fusion with IMU

6. **✅ Proven in Education**
   - LEGO Education standard
   - Used in FLL, WRO, educational robotics
   - Extensive community support
   - Many examples to learn from

**Trade-off:**
- ⚠️ Slower (0.4 m/s vs 1.25 m/s)
- ✅ BUT: Tight turning compensates
- ✅ And WRO often values precision > speed

---

## 🏗️ Build HAT Architecture (Option 1)

```
┌─────────────────────────────────────────────────┐
│ Raspberry Pi 5 (16GB)                           │
│ ┌─────────────────────────────────────────────┐ │
│ │ ROS2 Humble                                 │ │
│ │ - YOLO vision (AI HAT+)                     │ │
│ │ - Navigation (Nav2)                         │ │
│ │ - diff_drive_controller                     │ │
│ │ - Mission config (YAML)                     │ │
│ └─────────────────────────────────────────────┘ │
│              │                                   │
│              ├─ GPIO Header                      │
│              │                                   │
│   ┌──────────▼────────────────┐                 │
│   │ Raspberry Pi Build HAT    │                 │
│   │ (RP2040 onboard)          │                 │
│   └───────────────────────────┘                 │
│    │      │      │      │                       │
└────┼──────┼──────┼──────┼───────────────────────┘
     │      │      │      │
   Port A Port B Port C Port D
     │      │      │      │
  LEGO   LEGO   Color  Distance
  Motor  Motor  Sensor Sensor
  Left   Right  (opt)  (opt)
```

**Clean Architecture:**
- Everything connects to Pi 5
- One power supply for Build HAT (URGENEX 7.4V)
- One power supply for Pi 5 (Shargeek)
- Simple wiring, reliable

---

## 📐 LEGO Chassis Design from Bugatti Bolide

**You Already Have:**
- ✅ LEGO beams (structure)
- ✅ LEGO axles (wheel mounting)
- ✅ LEGO gears (power transmission)
- ✅ LEGO connectors (assembly)
- ✅ 905 parts total!

**Simple Differential Chassis Design:**

```
Top View:
┌─────────────────────────────────┐
│  [Camera Module 3]              │
│                                 │
│  [Raspberry Pi 5]               │
│  [AI HAT+]                      │
│                                 │
│  [RPLiDAR C1]                   │
│                                 │
│  ┌──────────────────────┐       │
│  │   Build HAT          │       │
│  └──────────────────────┘       │
│                                 │
│  [Battery: Shargeek]            │
│                                 │
├─[Motor L]──────────[Motor R]───┤
│     │                  │        │
│   Wheel              Wheel      │
│                                 │
│   [Wheel]          [Wheel]      │ (Rear casters/omni)
└─────────────────────────────────┘

Side View:
        ┌─────────┐
        │ Pi5+HAT+│
        │ Sensors │
        └────┬────┘
             │
   ┌─────────┴─────────┐
   │  LEGO Frame       │
   │   (Beams)         │
   └─┬───────────────┬─┘
     │               │
  [Motor]         [Motor]
     │               │
   Wheel           Wheel
```

**Build Steps:**
1. Create base frame (LEGO beams)
2. Mount motors on sides (differential drive)
3. Add rear caster wheels (LEGO omni wheels)
4. Mount Pi 5 + Build HAT on top
5. Add sensors (Camera, LiDAR, IMU)
6. Wire everything up
7. Done!

**Estimated Build Time:** 4-6 hours

---

## 💰 Cost Comparison (All Options)

| Option | Cost | Speed | Complexity | Best For |
|---|---|---|---|---|
| **1. Full LEGO (Differential)** | $73-103 | 0.4 m/s | ⭐ Easy | **WRO** |
| **2. Hybrid INJORA+LEGO** | $78-98 | 1.25 m/s | ⭐⭐ Medium | Speed tracks |
| **3. Keep INJORA+Servo** | $38 | 1.25 m/s | ⭐⭐ Medium | Budget + Speed |
| 4. Full LEGO (Ackermann) | $60-90 | 0.4 m/s | ⭐⭐⭐ Hard | Car-like |

---

## ✅ My Final Recommendation

### **Option 1: Full LEGO Differential System** 🏆

**Purchase List:**
- [ ] 2× LEGO Technic Large Motor 88013 ($40-60)
- [ ] 1× Raspberry Pi Build HAT ($25-35)
- [ ] 1× TCS34725 color sensor ($8)
- **Total: $73-103**

**Use What You Have:**
- ✅ Bugatti Bolide 905 LEGO Technic parts
- ✅ Raspberry Pi 5 (16GB)
- ✅ AI HAT+ 26 TOPS
- ✅ Camera, LiDAR, IMU, batteries

**Why This Wins:**

1. **Configuration Flexibility** ✅
   - JSON/YAML configs (your #1 requirement!)
   - ROS2 diff_drive_controller
   - Behavior trees
   - Perfect for surprise rules

2. **Simplicity** ✅
   - Simplest mechanical design
   - Simplest ROS2 integration
   - Plug & play Build HAT
   - No Pico 2W needed

3. **Reliability** ✅
   - LEGO Education standard
   - Proven hardware
   - Community support
   - Easy to debug

4. **WRO Performance** ✅
   - Zero turning radius (best!)
   - Precise positioning
   - Good enough speed for WRO
   - Tight space navigation

5. **Build Experience** ✅
   - Use your Bugatti Bolide parts!
   - LEGO = easy assembly/modification
   - Professional appearance
   - Fun to build!

**Trade-offs Accepted:**
- ⚠️ Slower than INJORA (0.4 vs 1.25 m/s)
- ✅ Compensated by zero turning radius
- ✅ WRO values precision over raw speed
- ✅ Can still complete courses competitively

---

## 🚀 Implementation Plan

### Week 1: Order & Design
- [ ] Order 2× LEGO Large Motor 88013
- [ ] Order 1× Build HAT
- [ ] Order 1× TCS34725
- [ ] Design chassis layout (sketch)

### Week 2: Mechanical Build
- [ ] Build differential chassis from Bugatti parts
- [ ] Mount motors
- [ ] Add caster wheels
- [ ] Mount Pi 5 + Build HAT
- [ ] Basic assembly complete

### Week 3: Electronics & Software
- [ ] Install Build HAT library (`pip install buildhat`)
- [ ] Test motor control (basic)
- [ ] Implement differential drive node (ROS2)
- [ ] Test Nav2 integration

### Week 4: Integration & Testing
- [ ] Add all sensors (Camera, LiDAR, IMU)
- [ ] Implement odometry fusion (EKF)
- [ ] Test YOLO + navigation
- [ ] Create mission config YAML

### Week 5-11: Competition Prep
- [ ] Fine-tune navigation
- [ ] Test on WRO-like courses
- [ ] Optimize performance
- [ ] Document everything

---

## 📊 Speed Analysis: Is 0.4 m/s Enough?

**LEGO Setup Speed:**
- Max speed: 0.4 m/s (24 m/min)
- Typical WRO course: 3m × 3m = 9 sqm
- Course perimeter: ~12m

**Time Estimates:**

| Task | INJORA (1.25 m/s) | LEGO (0.4 m/s) |
|---|---|---|
| **Straight line (3m)** | 2.4 sec | 7.5 sec |
| **Turn in place (180°)** | 1 sec | 1 sec ⭐ |
| **Navigate obstacles** | 15 sec | 20 sec |
| **Complete lap** | ~30 sec | ~45 sec |

**Analysis:**
- ⚠️ 50% slower on straights
- ✅ Same turning time (zero radius!)
- ✅ Better precision = fewer corrections
- ✅ Typical WRO run: 2-3 minutes
- ✅ 15-second difference won't matter if reliable!

**Bottom Line:**
- LEGO is slower but more reliable
- **Reliability > Raw Speed** for competitions
- Fewer retries due to errors = better final time
- **Speed is acceptable for WRO!**

---

## 🔗 Resources

### Build HAT:
- [Raspberry Pi Build HAT Documentation](https://www.raspberrypi.com/documentation/accessories/build-hat.html)
- [Build HAT Python Library](https://buildhat.readthedocs.io/en/latest/buildhat/index.html)
- [Meet the Build HAT (Raspberry Pi News)](https://www.raspberrypi.com/news/raspberry-pi-build-hat-lego-education/)

### LEGO Motors:
- [LEGO Technic Large Motor 88013](https://www.lego.com/en-us/product/technic-large-motor-88013)
- [LEGO Technic Medium Motor 45603](https://education.lego.com/en-us/products/lego-technic-medium-angular-motor/45603/)

### Differential Steering:
- [ROS2 diff_drive_controller](https://control.ros.org/master/doc/ros2_controllers/diff_drive_controller/doc/userdoc.html)
- [Differential Drive Kinematics](https://www.cs.columbia.edu/~allen/F17/NOTES/icckinematics.pdf)

### Community:
- [LEGO Technic Motors Guide (ZENE)](https://www.zenebricks.com/blogs/parts/lego-technic-motors-and-mechanical-sets)
- [LEGO Robot Car Tutorial (Code Club)](https://projects.raspberrypi.org/en/projects/lego-robot-car)

---

## ✅ Summary

**Question:** Should I use 2 LEGO Large Motors (one for drive, one for steering)?

**Answer:** **YES, but use differential steering (both for drive)!**

**Recommended Setup:**
- ✅ 2× LEGO Large Motor 88013 (differential drive)
- ✅ 1× Raspberry Pi Build HAT
- ✅ Chassis from Bugatti Bolide parts
- ✅ ROS2 + diff_drive_controller
- ✅ JSON/YAML configuration
- ✅ Total: $73-103

**Why It's Best:**
1. ✅ Simplest setup (no Ackermann linkage)
2. ✅ Perfect for WRO (zero turning radius)
3. ✅ Uses your LEGO parts
4. ✅ Meets configuration requirement
5. ✅ Reliable and proven
6. ✅ Good enough speed (0.4 m/s)

**Alternative (If Speed Critical):**
- Keep INJORA motor (1.25 m/s)
- Add PMW3901 optical flow ($30)
- Total: $38
- Trade-off: More complex, no LEGO integration

**Winner for YOU: Full LEGO Differential System!** 🏆

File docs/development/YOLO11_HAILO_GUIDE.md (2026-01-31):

# YOLO11 + Hailo 8L Integration Guide

## Overview

**YOLO11** (released by Ultralytics in late 2024) is the latest and most efficient YOLO model. Combined with Hailo 8L acceleration, you can achieve **30-60 FPS** on Raspberry Pi 5 for sign detection.

**Why YOLO11?**
- ✅ **Fastest inference** - 20-30% faster than YOLOv8
- ✅ **Better accuracy** - Improved architecture
- ✅ **Smaller models** - YOLO11n (nano) perfect for edge devices
- ✅ **Hailo support** - Works with Hailo 8L via ONNX conversion
- ✅ **Same API** - Drop-in replacement for YOLOv8

---

## Architecture Overview

```
┌─────────────────────────────────────────────────┐
│               Training (Laptop)                 │
│                                                 │
│  Collect Data → Label → Train YOLO11n          │
│                          ↓                      │
│                    checkpoint.pt                │
│                          ↓                      │
│                   Export to ONNX                │
│                          ↓                      │
│                    model.onnx                   │
└─────────────────────────────────────────────────┘
                          ↓
                   Transfer to RPi5
                          ↓
┌─────────────────────────────────────────────────┐
│          Hailo Conversion (RPi5 or Laptop)      │
│                                                 │
│  model.onnx → Hailo Compiler → model.hef        │
│                                                 │
└─────────────────────────────────────────────────┘
                          ↓
┌─────────────────────────────────────────────────┐
│            Inference (RPi5 + Hailo 8L)          │
│                                                 │
│  Camera → YOLO11 (Hailo) → Detections → ROS2   │
│           13 TOPS @ 4W                          │
│           30-60 FPS @ 640x480                   │
└─────────────────────────────────────────────────┘
```

---

## Phase 1: Training YOLO11 on Your Laptop

### Step 1.1: Install Ultralytics (Laptop)

```bash
# In WSL2
pip3 install ultralytics

# Verify installation
yolo version
# Should show: Ultralytics YOLO11...

# Test GPU
python3 -c "import torch; print(f'CUDA: {torch.cuda.is_available()}')"
# Should show: CUDA: True (if RTX 4050 is configured)
```

### Step 1.2: Prepare Dataset

**Directory structure:**
```
~/teamsteelbot_ws/datasets/traffic_signs/
├── images/
│   ├── train/
│   │   ├── img001.jpg
│   │   ├── img002.jpg
│   │   └── ...
│   └── val/
│       ├── img101.jpg
│       └── ...
├── labels/
│   ├── train/
│   │   ├── img001.txt  # YOLO format labels
│   │   ├── img002.txt
│   │   └── ...
│   └── val/
│       ├── img101.txt
│       └── ...
└── data.yaml
```

**data.yaml:**
```yaml
# Dataset configuration for YOLO11

path: /home/your_user/teamsteelbot_ws/datasets/traffic_signs
train: images/train
val: images/val

# Classes
nc: 3  # Number of classes
names: ['red_sign', 'green_sign', 'blue_sign']
```

### Step 1.3: Data Collection Strategies

**Option A: Real images (Best accuracy)**
```bash
# Capture images from mock camera or real camera
ros2 run teamsteelbot_tools image_capturer --output-dir ~/datasets/raw_images

# Label with Roboflow (easiest) or LabelImg
# Roboflow: https://roboflow.com (free tier)
# Export in YOLO format
```

**Option B: Synthetic data (Fastest to start)**
```python
# Create synthetic training data
# File: ~/teamsteelbot_ws/src/teamsteelbot_tools/scripts/generate_synthetic_data.py

import cv2
import numpy as np
import os
from pathlib import Path

def generate_sign_image(sign_color, img_id, output_dir):
    """Generate synthetic sign image with label"""
    # Create image (640x480)
    img = np.random.randint(100, 150, (480, 640, 3), dtype=np.uint8)

    # Random sign position
    sign_w, sign_h = np.random.randint(80, 150), np.random.randint(100, 180)
    x = np.random.randint(50, 640 - sign_w - 50)
    y = np.random.randint(50, 480 - sign_h - 50)

    # Color map
    colors = {
        'red': (0, 0, 255),
        'green': (0, 255, 0),
        'blue': (255, 0, 0),
    }
    color = colors[sign_color]

    # Draw sign
    cv2.rectangle(img, (x, y), (x + sign_w, y + sign_h), color, -1)
    cv2.rectangle(img, (x, y), (x + sign_w, y + sign_h), (255, 255, 255), 3)

    # Add some noise/variation
    noise = np.random.randint(-20, 20, img.shape, dtype=np.int16)
    img = np.clip(img.astype(np.int16) + noise, 0, 255).astype(np.uint8)

    # Save image
    img_path = output_dir / 'images' / f'{img_id:04d}.jpg'
    cv2.imwrite(str(img_path), img)

    # Create YOLO label (normalized coordinates)
    label_path = output_dir / 'labels' / f'{img_id:04d}.txt'
    class_id = {'red': 0, 'green': 1, 'blue': 2}[sign_color]
    x_center = (x + sign_w / 2) / 640
    y_center = (y + sign_h / 2) / 480
    width = sign_w / 640
    height = sign_h / 480

    with open(label_path, 'w') as f:
        f.write(f'{class_id} {x_center:.6f} {y_center:.6f} {width:.6f} {height:.6f}\n')

# Generate dataset
output_dir = Path('~/teamsteelbot_ws/datasets/traffic_signs/train')
output_dir.mkdir(parents=True, exist_ok=True)
(output_dir / 'images').mkdir(exist_ok=True)
(output_dir / 'labels').mkdir(exist_ok=True)

# Generate 1000 training images (333 each color)
img_id = 0
for _ in range(333):
    for color in ['red', 'green', 'blue']:
        generate_sign_image(color, img_id, output_dir)
        img_id += 1

print(f'Generated {img_id} synthetic training images')
```

**Option C: Mix of real + synthetic (Recommended)**
- Start with 200-500 synthetic images (quick baseline)
- Add 50-100 real images for fine-tuning
- Best balance of speed and accuracy

### Step 1.4: Train YOLO11

```bash
# Train YOLO11-nano (smallest, fastest)
yolo detect train \
  data=~/teamsteelbot_ws/datasets/traffic_signs/data.yaml \
  model=yolo11n.pt \
  epochs=100 \
  imgsz=640 \
  batch=16 \
  device=0 \
  project=~/teamsteelbot_ws/models \
  name=traffic_signs_yolo11n

# Training will take 30-60 minutes on RTX 4050
# Model saved to: ~/teamsteelbot_ws/models/traffic_signs_yolo11n/weights/best.pt
```

**Training parameters explained:**
- `model=yolo11n.pt` - Nano model (fastest, smallest)
- `epochs=100` - Training iterations (adjust based on dataset size)
- `imgsz=640` - Input image size (640x640, Hailo optimized)
- `batch=16` - Batch size (reduce if out of memory)
- `device=0` - Use GPU 0 (RTX 4050)

**Alternative models (if nano is not accurate enough):**
```bash
# YOLO11-small (better accuracy, slightly slower)
yolo detect train data=data.yaml model=yolo11s.pt epochs=100

# YOLO11-medium (best accuracy, slowest)
yolo detect train data=data.yaml model=yolo11m.pt epochs=100
```

### Step 1.5: Evaluate Model

```bash
# Test on validation set
yolo detect val \
  model=~/teamsteelbot_ws/models/traffic_signs_yolo11n/weights/best.pt \
  data=~/teamsteelbot_ws/datasets/traffic_signs/data.yaml

# Test on single image
yolo detect predict \
  model=~/teamsteelbot_ws/models/traffic_signs_yolo11n/weights/best.pt \
  source=~/test_images/test_sign.jpg \
  save=True
```

**Target metrics:**
- **mAP@0.5:** >0.85 (85% accuracy)
- **Precision:** >0.90
- **Recall:** >0.85
- **Inference time (laptop):** <10ms

### Step 1.6: Export to ONNX

```bash
# Export to ONNX format (required for Hailo)
yolo export \
  model=~/teamsteelbot_ws/models/traffic_signs_yolo11n/weights/best.pt \
  format=onnx \
  imgsz=640 \
  simplify=True

# Output: best.onnx
# This file will be converted to Hailo HEF format
```

---

## Phase 2: Convert ONNX to Hailo HEF

### Option A: On Laptop (Recommended if you have Hailo Dataflow Compiler)

```bash
# Install Hailo Dataflow Compiler
# (Follow Hailo's installation guide for your system)
# Download from: https://hailo.ai/developer-zone/

# Convert ONNX to HEF
hailo parser onnx best.onnx

hailo optimize \
  --hw-arch hailo8l \
  --input-model best.hn \
  --output-model best_optimized.har

hailo compile \
  --hw-arch hailo8l \
  --input-model best_optimized.har \
  --output-model traffic_signs_yolo11n.hef
```

### Option B: On Raspberry Pi 5 (Simpler, no separate compiler needed)

The Hailo runtime on RPi5 can sometimes use ONNX directly, or you can use pre-built conversion tools.

```bash
# On RPi5, install Hailo Python API
pip3 install hailort

# Use Hailo's model conversion script (if available)
# Or transfer HEF from laptop
```

### Option C: Use Hailo Model Zoo (Easiest)

```bash
# Clone Hailo Model Zoo
git clone https://github.com/hailo-ai/hailo_model_zoo.git
cd hailo_model_zoo

# Check if YOLO11 is available
# If not, use their conversion scripts for custom models
python hailo_model_zoo/main.py parse \
  --hw-arch hailo8l \
  --ckpt best.onnx \
  --output-model traffic_signs.har

python hailo_model_zoo/main.py compile \
  --hw-arch hailo8l \
  --har traffic_signs.har \
  --output-model traffic_signs.hef
```

---

## Phase 3: ROS2 Integration (Laptop Development)

### Step 3.1: YOLO11 Detector Node (Development Version - CPU/GPU)

First, develop and test on laptop using ONNX Runtime or PyTorch.

**File:** `~/teamsteelbot_ws/src/teamsteelbot_vision/teamsteelbot_vision/sign_detector_yolo11.py`

```python
#!/usr/bin/env python3
"""
YOLO11 sign detector for ROS2
Development version: Uses ONNX Runtime (works on laptop and RPi5)
Production version: Uses Hailo runtime (RPi5 only)
"""

import rclpy
from rclpy.node import Node
from sensor_msgs.msg import Image
from vision_msgs.msg import Detection2D, Detection2DArray, ObjectHypothesisWithPose
from cv_bridge import CvBridge
import cv2
import numpy as np

# Development: Use ONNX Runtime
import onnxruntime as ort

# Production (RPi5): Use Hailo
# from hailo_platform import HEF, VDevice, HailoStreamInterface, InferVStreams

class SignDetectorYOLO11(Node):
    def __init__(self):
        super().__init__('sign_detector_yolo11')

        # Parameters
        self.declare_parameter('model_path',
            '~/teamsteelbot_ws/models/traffic_signs_yolo11n/weights/best.onnx')
        self.declare_parameter('use_hailo', False)  # True on RPi5, False on laptop
        self.declare_parameter('confidence_threshold', 0.5)
        self.declare_parameter('iou_threshold', 0.45)

        model_path = self.get_parameter('model_path').value
        self.use_hailo = self.get_parameter('use_hailo').value
        self.conf_threshold = self.get_parameter('confidence_threshold').value
        self.iou_threshold = self.get_parameter('iou_threshold').value

        # Class names
        self.class_names = ['red_sign', 'green_sign', 'blue_sign']

        # Load model
        if self.use_hailo:
            self.load_hailo_model(model_path)
        else:
            self.load_onnx_model(model_path)

        # ROS2 setup
        self.subscription = self.create_subscription(
            Image, '/camera/image_raw', self.image_callback, 10
        )
        self.detection_pub = self.create_publisher(Detection2DArray, '/detections', 10)
        self.debug_pub = self.create_publisher(Image, '/detections/debug_image', 10)

        self.bridge = CvBridge()

        self.get_logger().info(f'YOLO11 detector started (Hailo: {self.use_hailo})')

    def load_onnx_model(self, model_path):
        """Load ONNX model for CPU/GPU inference (laptop development)"""
        self.get_logger().info(f'Loading ONNX model: {model_path}')

        # ONNX Runtime session
        providers = ['CUDAExecutionProvider', 'CPUExecutionProvider']
        self.session = ort.InferenceSession(model_path, providers=providers)

        # Get input shape
        self.input_name = self.session.get_inputs()[0].name
        self.input_shape = self.session.get_inputs()[0].shape
        self.input_height = self.input_shape[2]  # 640
        self.input_width = self.input_shape[3]   # 640

        self.get_logger().info(f'Model loaded: {self.input_width}x{self.input_height}')

    def load_hailo_model(self, model_path):
        """Load Hailo HEF model (RPi5 production)"""
        self.get_logger().info(f'Loading Hailo model: {model_path}')

        # This will be implemented when deploying to RPi5
        # For now, we'll use ONNX on laptop
        raise NotImplementedError("Hailo support coming soon - use use_hailo:=false for now")

    def preprocess_image(self, cv_image):
        """Preprocess image for YOLO11 input"""
        # Resize to model input size
        img = cv2.resize(cv_image, (self.input_width, self.input_height))

        # Convert BGR to RGB
        img = cv2.cvtColor(img, cv2.COLOR_BGR2RGB)

        # Normalize to [0, 1]
        img = img.astype(np.float32) / 255.0

        # Transpose to CHW format (channels first)
        img = img.transpose(2, 0, 1)

        # Add batch dimension
        img = np.expand_dims(img, axis=0)

        return img

    def postprocess_detections(self, outputs, orig_shape):
        """Convert YOLO11 outputs to bounding boxes"""
        # YOLO11 output format: [batch, num_boxes, 5 + num_classes]
        # [x_center, y_center, width, height, confidence, class_scores...]

        predictions = outputs[0]  # Remove batch dimension

        detections = []

        for pred in predictions:
            # Parse prediction
            x_center, y_center, w, h = pred[0:4]
            confidence = pred[4]
            class_scores = pred[5:]

            # Filter by confidence
            if confidence < self.conf_threshold:
                continue

            # Get class with highest score
            class_id = np.argmax(class_scores)
            class_score = class_scores[class_id]

            # Combined score
            score = confidence * class_score

            if score < self.conf_threshold:
                continue

            # Convert to pixel coordinates
            orig_h, orig_w = orig_shape[:2]
            x_center_px = x_center * orig_w / self.input_width
            y_center_px = y_center * orig_h / self.input_height
            w_px = w * orig_w / self.input_width
            h_px = h * orig_h / self.input_height

            detections.append({
                'bbox': [x_center_px, y_center_px, w_px, h_px],
                'class_id': int(class_id),
                'class_name': self.class_names[class_id],
                'confidence': float(score)
            })

        # Apply NMS (Non-Maximum Suppression)
        detections = self.apply_nms(detections)

        return detections

    def apply_nms(self, detections):
        """Apply Non-Maximum Suppression to remove duplicate detections"""
        if len(detections) == 0:
            return []

        # Convert to format for cv2.dnn.NMSBoxes
        boxes = []
        confidences = []

        for det in detections:
            x_c, y_c, w, h = det['bbox']
            x1 = int(x_c - w / 2)
            y1 = int(y_c - h / 2)
            boxes.append([x1, y1, int(w), int(h)])
            confidences.append(det['confidence'])

        # Apply NMS
        indices = cv2.dnn.NMSBoxes(boxes, confidences,
                                   self.conf_threshold, self.iou_threshold)

        # Return filtered detections
        if len(indices) > 0:
            return [detections[i] for i in indices.flatten()]
        else:
            return []

    def image_callback(self, msg):
        """Process incoming image"""
        # Convert ROS Image to OpenCV
        cv_image = self.bridge.imgmsg_to_cv2(msg, desired_encoding='bgr8')
        orig_shape = cv_image.shape

        # Preprocess
        input_tensor = self.preprocess_image(cv_image)

        # Inference
        outputs = self.session.run(None, {self.input_name: input_tensor})

        # Postprocess
        detections = self.postprocess_detections(outputs[0][0], orig_shape)

        # Create ROS2 detection messages
        detection_array = Detection2DArray()
        detection_array.header = msg.header

        debug_image = cv_image.copy()

        for det in detections:
            # Create Detection2D message
            detection = Detection2D()
            detection.header = msg.header

            # Bounding box
            x_c, y_c, w, h = det['bbox']
            detection.bbox.center.position.x = x_c
            detection.bbox.center.position.y = y_c
            detection.bbox.size_x = w
            detection.bbox.size_y = h

            # Classification
            hypothesis = ObjectHypothesisWithPose()
            hypothesis.hypothesis.class_id = det['class_name']
            hypothesis.hypothesis.score = det['confidence']
            detection.results.append(hypothesis)

            detection_array.detections.append(detection)

            # Draw on debug image
            x1 = int(x_c - w / 2)
            y1 = int(y_c - h / 2)
            x2 = int(x_c + w / 2)
            y2 = int(y_c + h / 2)

            color = {
                'red_sign': (0, 0, 255),
                'green_sign': (0, 255, 0),
                'blue_sign': (255, 0, 0),
            }[det['class_name']]

            cv2.rectangle(debug_image, (x1, y1), (x2, y2), color, 2)
            cv2.putText(debug_image,
                       f"{det['class_name']} {det['confidence']:.2f}",
                       (x1, y1 - 10),
                       cv2.FONT_HERSHEY_SIMPLEX, 0.5, color, 2)

        # Publish
        self.detection_pub.publish(detection_array)

        debug_msg = self.bridge.cv2_to_imgmsg(debug_image, encoding='bgr8')
        debug_msg.header = msg.header
        self.debug_pub.publish(debug_msg)

        if detections:
            self.get_logger().info(f'Detected {len(detections)} signs')

def main(args=None):
    rclpy.init(args=args)
    node = SignDetectorYOLO11()

    try:
        rclpy.spin(node)
    except KeyboardInterrupt:
        pass
    finally:
        node.destroy_node()
        rclpy.shutdown()

if __name__ == '__main__':
    main()
```

### Step 3.2: Install Dependencies

```bash
# ONNX Runtime (for laptop development)
pip3 install onnxruntime-gpu  # GPU version
# Or: pip3 install onnxruntime  # CPU only

# Test
python3 -c "import onnxruntime; print(onnxruntime.get_device())"
```

### Step 3.3: Test on Laptop

```bash
# Terminal 1: Mock camera
ros2 run teamsteelbot_simulation mock_camera_node

# Terminal 2: YOLO11 detector
ros2 run teamsteelbot_vision sign_detector_yolo11 --ros-args \
  -p model_path:=~/teamsteelbot_ws/models/traffic_signs_yolo11n/weights/best.onnx \
  -p use_hailo:=false

# Terminal 3: View detections
ros2 topic echo /detections

# Terminal 4: View debug image in RViz2
rviz2
# Add Image display → /detections/debug_image
```

---

## Phase 4: Hailo Integration (RPi5 Only)

### Step 4.1: Install Hailo Runtime on RPi5

```bash
# On Raspberry Pi 5
# Install Hailo PCIe driver
sudo apt update
sudo apt install hailo-all

# Install Python bindings
pip3 install hailort

# Verify Hailo device
hailortcli fw-control identify
# Should show: Hailo-8L detected
```

### Step 4.2: Hailo-Optimized Detector Node

**File:** `sign_detector_yolo11_hailo.py` (create separate file for RPi5)

```python
#!/usr/bin/env python3
"""
YOLO11 detector with native Hailo acceleration (RPi5 only)
"""

import rclpy
from rclpy.node import Node
from sensor_msgs.msg import Image
from vision_msgs.msg import Detection2DArray, ObjectHypothesisWithPose
from cv_bridge import CvBridge
import cv2
import numpy as np

from hailo_platform import (HEF, ConfigureParams, FormatType, HailoStreamInterface,
                            InferVStreams, InputVStreamParams, OutputVStreamParams,
                            VDevice)

class SignDetectorYOLO11Hailo(Node):
    def __init__(self):
        super().__init__('sign_detector_yolo11_hailo')

        # Parameters
        self.declare_parameter('model_path',
            '~/teamsteelbot_ws/models/traffic_signs_yolo11n.hef')
        self.declare_parameter('confidence_threshold', 0.5)

        model_path = self.get_parameter('model_path').value
        self.conf_threshold = self.get_parameter('confidence_threshold').value

        # Class names
        self.class_names = ['red_sign', 'green_sign', 'blue_sign']

        # Initialize Hailo
        self.init_hailo(model_path)

        # ROS2 setup
        self.subscription = self.create_subscription(
            Image, '/camera/image_raw', self.image_callback, 10
        )
        self.detection_pub = self.create_publisher(Detection2DArray, '/detections', 10)
        self.debug_pub = self.create_publisher(Image, '/detections/debug_image', 10)

        self.bridge = CvBridge()

        self.get_logger().info('YOLO11 Hailo detector started')

    def init_hailo(self, hef_path):
        """Initialize Hailo device and load model"""
        self.get_logger().info(f'Loading Hailo model: {hef_path}')

        # Load HEF
        self.hef = HEF(hef_path)

        # Create VDevice (virtual device)
        self.target = VDevice()

        # Configure network group
        self.network_group = self.target.configure(self.hef)[0]
        self.network_group_params = self.network_group.create_params()

        # Get input/output shapes
        self.input_vstream_info = self.hef.get_input_vstream_infos()[0]
        self.output_vstream_info = self.hef.get_output_vstream_infos()[0]

        self.input_shape = self.input_vstream_info.shape
        self.input_height = self.input_shape[0]
        self.input_width = self.input_shape[1]

        self.get_logger().info(f'Hailo initialized: {self.input_width}x{self.input_height}')

    def preprocess_image(self, cv_image):
        """Preprocess image for Hailo input"""
        # Resize
        img = cv2.resize(cv_image, (self.input_width, self.input_height))

        # Hailo expects uint8 input (no normalization needed)
        return img

    def image_callback(self, msg):
        """Process incoming image with Hailo"""
        # Convert ROS Image to OpenCV
        cv_image = self.bridge.imgmsg_to_cv2(msg, desired_encoding='bgr8')
        orig_shape = cv_image.shape

        # Preprocess
        input_data = self.preprocess_image(cv_image)

        # Hailo inference
        with InferVStreams(self.network_group,
                          InputVStreamParams.make_from_network_group(self.network_group, quantized=False),
                          OutputVStreamParams.make_from_network_group(self.network_group, quantized=False)) as infer_pipeline:

            # Run inference
            input_dict = {self.input_vstream_info.name: input_data}
            output_dict = infer_pipeline.infer(input_dict)

            # Get output
            output_data = list(output_dict.values())[0]

        # Postprocess (similar to ONNX version)
        detections = self.postprocess_detections(output_data, orig_shape)

        # Publish detections (same as ONNX version)
        # ... (copy from ONNX version)

        if detections:
            self.get_logger().info(f'Detected {len(detections)} signs @ Hailo')

def main(args=None):
    rclpy.init(args=args)
    node = SignDetectorYOLO11Hailo()

    try:
        rclpy.spin(node)
    except KeyboardInterrupt:
        pass
    finally:
        node.destroy_node()
        rclpy.shutdown()

if __name__ == '__main__':
    main()
```

### Step 4.3: Test on RPi5

```bash
# On RPi5
ros2 run teamsteelbot_vision sign_detector_yolo11_hailo --ros-args \
  -p model_path:=~/teamsteelbot_ws/models/traffic_signs_yolo11n.hef

# Should achieve 30-60 FPS with Hailo acceleration!
```

---

## Performance Comparison

| Platform | Model | Backend | FPS | Latency |
|---|---|---|-----|---|
| Laptop (RTX 4050) | YOLO11n | ONNX GPU | 200+ | ~5ms |
| RPi5 | YOLO11n | ONNX CPU | 10-15 | ~70ms |
| **RPi5 + Hailo 8L** | **YOLO11n** | **Hailo** | **30-60** | **~20ms** |

**Hailo advantage: 3-4x speedup vs CPU!**

---

## Troubleshooting

### Issue: Low FPS on Hailo
**Solution:** Check if model is actually using Hailo
```bash
hailortcli run model.hef
# Should show GPU utilization
```

### Issue: ONNX model conversion fails
**Solution:** Simplify export
```bash
yolo export model=best.pt format=onnx imgsz=640 simplify=True opset=11
```

### Issue: Different results on Hailo vs ONNX
**Solution:** This is expected due to quantization. Retrain with quantization-aware training if needed.

---

## Summary: Development Workflow

```
┌─────────────────────────────────────────┐
│  Week 1-2: Train on Laptop (RTX 4050)  │
│  → Collect data, train YOLO11n          │
│  → Export to ONNX                       │
│  → Test with ONNX Runtime (200+ FPS)    │
└─────────────────────────────────────────┘
              ↓
┌─────────────────────────────────────────┐
│  Week 3-6: Develop Logic on Laptop     │
│  → ROS2 nodes with ONNX backend         │
│  → State machine, control logic         │
│  → Full simulation                      │
└─────────────────────────────────────────┘
              ↓
┌─────────────────────────────────────────┐
│  Week 7-8: Port to RPi5                 │
│  → Convert ONNX to Hailo HEF            │
│  → Test Hailo performance (30-60 FPS)   │
│  → Integrate with real sensors          │
└─────────────────────────────────────────┘
              ↓
┌─────────────────────────────────────────┐
│  Week 9+: Physical Testing              │
│  → Track testing with Hailo             │
│  → Fine-tune, optimize                  │
│  → Competition ready! 🏁                │
└─────────────────────────────────────────┘
```

---

## Next Steps

1. **Install Ultralytics:** `pip3 install ultralytics`
2. **Generate synthetic dataset** (or collect real images)
3. **Train YOLO11n:** `yolo detect train data=data.yaml model=yolo11n.pt`
4. **Export to ONNX:** `yolo export model=best.pt format=onnx`
5. **Integrate with ROS2** (use starter code above)
6. **Test on laptop** with ONNX Runtime
7. **Port to RPi5** and convert to Hailo HEF

**YOLO11 + Hailo = 30-60 FPS sign detection on edge device! 🚀**

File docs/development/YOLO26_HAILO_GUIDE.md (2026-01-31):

# YOLO26 + Hailo 8L Integration Guide

## Overview

**YOLO26** (released January 14, 2026) is Ultralytics' latest and most advanced YOLO model, specifically engineered for edge and low-power devices. Combined with Hailo 8L acceleration, it represents the cutting edge of real-time object detection on Raspberry Pi 5.

**Key Innovation:** End-to-end NMS-free architecture + 43% faster CPU inference

**Release Date:** January 14, 2026 (Official release)
**Announcement:** September 25, 2025 (YOLO Vision 2025, London)

---

## Why YOLO26? 🚀

### Revolutionary Improvements Over YOLO11

| Feature | YOLO11 | YOLO26 | Improvement |
|---|---|---|---|
| **CPU Inference Speed** | Baseline | **+43% faster** | 🚀 Huge! |
| **mAP (COCO, nano)** | 39.5 | **40.9** | +3.5% |
| **NMS Required** | Yes | **No (native E2E)** | ✅ Simpler |
| **Export Compatibility** | Good | **Excellent** | ✅ Better |
| **Edge Optimization** | Good | **Exceptional** | ✅ Purpose-built |
| **Quantization Resilience** | Good | **Better** | ✅ Hailo-friendly |

### Core Innovations

1. **End-to-End NMS-Free Architecture**
   - Predictions generated directly without post-processing
   - Reduces latency significantly
   - Simpler deployment pipeline

2. **43% Faster CPU Inference**
   - Critical for Raspberry Pi 5
   - Better performance even without Hailo
   - Optimized for ARM architecture

3. **DFL Removal**
   - Simplified architecture
   - Broader hardware compatibility
   - Better ONNX/TensorRT export

4. **MuSGD Optimizer**
   - Hybrid SGD + Muon algorithm
   - More stable training
   - Faster convergence

5. **ProgLoss + STAL**
   - Better small object detection
   - Improved accuracy
   - Better for traffic signs!

---

## Architecture Overview

```
┌─────────────────────────────────────────────────┐
│           Training (Laptop - RTX 4050)          │
│                                                 │
│  Dataset → Train YOLO26n → Export ONNX         │
│            (30 min)         (1 min)            │
│                                                 │
│  Performance: 40.9 mAP, 200+ FPS on GPU        │
└─────────────────────────────────────────────────┘
                          ↓
                   Transfer to RPi5
                          ↓
┌─────────────────────────────────────────────────┐
│       Hailo Conversion (When Supported)         │
│                                                 │
│  ONNX → Hailo Compiler → HEF                   │
│                                                 │
│  NOTE: Official Hailo support pending          │
│  (Model released Jan 2026, very new)           │
└─────────────────────────────────────────────────┘
                          ↓
┌─────────────────────────────────────────────────┐
│         Inference (RPi5 + Hailo 8L)             │
│                                                 │
│  Option A: YOLO26 ONNX (CPU) - 15-20 FPS       │
│  Option B: YOLO26 HEF (Hailo) - 40-80 FPS*     │
│  Option C: YOLO11 HEF (Hailo) - 30-60 FPS      │
│                                                 │
│  *Estimated based on 43% speedup over YOLO11   │
└─────────────────────────────────────────────────┘
```

---

## Phase 1: Training YOLO26 on Laptop

### Step 1.1: Install Latest Ultralytics

```bash
# Update to latest version with YOLO26 support
pip3 install --upgrade ultralytics

# Verify YOLO26 is available
yolo version
# Should show: Ultralytics 8.3.x or later

# Test YOLO26
python3 -c "from ultralytics import YOLO; model = YOLO('yolo26n.pt'); print('YOLO26 ready!')"
```

### Step 1.2: Prepare Dataset

**Directory structure:**
```
~/teamsteelbot_ws/datasets/traffic_signs/
├── images/
│   ├── train/
│   │   ├── img001.jpg
│   │   └── ...
│   └── val/
│       └── ...
├── labels/
│   ├── train/
│   │   ├── img001.txt  # YOLO format
│   │   └── ...
│   └── val/
│       └── ...
└── data.yaml
```

**Generate synthetic dataset (fastest way to start):**
```bash
# Use the provided script
python3 scripts/generate_synthetic_dataset.py \
  --num-images 1000 \
  --output-dir ~/teamsteelbot_ws/datasets/traffic_signs

# Takes ~2 minutes, creates 1000 labeled images
```

**data.yaml:**
```yaml
# ~/teamsteelbot_ws/datasets/traffic_signs/data.yaml
path: /home/your_user/teamsteelbot_ws/datasets/traffic_signs
train: images/train
val: images/val

nc: 3
names: ['red_sign', 'green_sign', 'blue_sign']
```

### Step 1.3: Train YOLO26-Nano

```bash
# Train YOLO26n (nano - smallest, fastest)
yolo detect train \
  data=~/teamsteelbot_ws/datasets/traffic_signs/data.yaml \
  model=yolo26n.pt \
  epochs=50 \
  imgsz=640 \
  batch=16 \
  device=0 \
  project=~/teamsteelbot_ws/models \
  name=signs_yolo26n \
  patience=10

# Training time: ~20-30 minutes on RTX 4050
# Model saved to: ~/teamsteelbot_ws/models/signs_yolo26n/weights/best.pt
```

**Training parameters explained:**
- `model=yolo26n.pt` - Nano variant (2.4M parameters, fastest)
- `epochs=50` - Good for 1k synthetic images
- `imgsz=640` - Standard size, Hailo-optimized
- `batch=16` - Adjust based on GPU memory
- `device=0` - Use GPU 0 (RTX 4050)
- `patience=10` - Early stopping if no improvement

**Alternative model sizes:**
```bash
# YOLO26s (small) - Better accuracy, slower
yolo detect train model=yolo26s.pt data=data.yaml epochs=50

# YOLO26m (medium) - Best accuracy, slowest
yolo detect train model=yolo26m.pt data=data.yaml epochs=50
```

### Step 1.4: Evaluate Model

```bash
# Validate on test set
yolo detect val \
  model=~/teamsteelbot_ws/models/signs_yolo26n/weights/best.pt \
  data=~/teamsteelbot_ws/datasets/traffic_signs/data.yaml

# Test on single image
yolo detect predict \
  model=~/teamsteelbot_ws/models/signs_yolo26n/weights/best.pt \
  source=~/test_images/test_sign.jpg \
  save=True \
  conf=0.5
```

**Target metrics:**
- **mAP@0.5:** >0.85 (traffic signs are easier than COCO)
- **Precision:** >0.90
- **Recall:** >0.85
- **Inference time (laptop GPU):** <5ms

### Step 1.5: Export to ONNX

```bash
# Export to ONNX (for laptop testing and Hailo conversion)
yolo export \
  model=~/teamsteelbot_ws/models/signs_yolo26n/weights/best.pt \
  format=onnx \
  imgsz=640 \
  simplify=True \
  opset=11 \
  nms=False

# Output: best.onnx
# Note: nms=False because YOLO26 is natively end-to-end!
```

**YOLO26 Export Advantage:**
- No NMS needed (native end-to-end)
- Simpler ONNX graph
- Better compatibility with edge devices
- Easier Hailo conversion (when supported)

---

## Phase 2: ONNX to Hailo HEF Conversion

### ⚠️ Important Note: Hailo Support Status

**As of January 31, 2026:**
- ✅ YOLO26 was released January 14, 2026 (2 weeks ago)
- ⏳ Official Hailo Model Zoo support is **pending**
- 🎯 Expected within 1-3 months (based on historical patterns)

**Your options:**

### Option A: Wait for Official Support (Recommended for Production)

```bash
# Check Hailo Model Zoo for YOLO26 support
git clone https://github.com/hailo-ai/hailo_model_zoo.git
cd hailo_model_zoo

# Look for yolo26 configs
ls hailo_model_zoo/cfg/networks/ | grep yolo26

# Monitor Hailo community
# https://community.hailo.ai/
```

**When support is added:**
```bash
# Standard conversion workflow
hailomz compile \
  --ckpt best.onnx \
  --hw-arch hailo8l \
  --yaml yolo26n.yaml \
  --calib-path ~/datasets/traffic_signs/images/val/ \
  --output-model best.hef
```

### Option B: Attempt Custom Conversion (Advanced, Experimental)

**Disclaimer:** This is untested. YOLO26 is very new.

```bash
# Try using YOLO11 config as template
cd hailo_model_zoo

# Copy YOLO11 config
cp hailo_model_zoo/cfg/networks/yolo11n.yaml \
   hailo_model_zoo/cfg/networks/yolo26n_custom.yaml

# Edit yolo26n_custom.yaml
# - Update input/output layer names
# - Adjust for NMS-free architecture
# - May need custom postprocessing

# Attempt compilation
hailomz compile \
  --ckpt best.onnx \
  --hw-arch hailo8l \
  --yaml yolo26n_custom.yaml \
  --calib-path ~/datasets/traffic_signs/images/val/ \
  --output-model best.hef

# This may or may not work - YOLO26 architecture is different
```

**Challenges:**
- NMS-free output format differs from YOLO11
- May need custom output layer mapping
- Quantization parameters might need tuning

### Option C: Use YOLO11 for Hailo (Fallback)

If you need Hailo acceleration NOW and can't wait:

```bash
# Train YOLO11 instead (proven Hailo support)
yolo detect train model=yolo11n.pt data=data.yaml epochs=50

# Export and convert (standard workflow)
yolo export model=best.pt format=onnx
hailomz compile --ckpt best.onnx --hw-arch hailo8l --yaml yolo11n.yaml
```

**Trade-off:**
- ❌ Miss YOLO26's 43% CPU speedup
- ❌ Slightly lower accuracy (39.5 vs 40.9 mAP)
- ✅ Proven to work on Hailo today
- ✅ All documentation applies

---

## Phase 3: ROS2 Integration (Laptop Development)

### Step 3.1: YOLO26 Detector Node (ONNX Runtime)

**File:** `~/teamsteelbot_ws/src/teamsteelbot_vision/teamsteelbot_vision/sign_detector_yolo26.py`

```python
#!/usr/bin/env python3
"""
YOLO26 sign detector for ROS2
Development version: Uses ONNX Runtime (laptop and RPi5)
Production version: Will use Hailo runtime when supported
"""

import rclpy
from rclpy.node import Node
from sensor_msgs.msg import Image
from vision_msgs.msg import Detection2D, Detection2DArray, ObjectHypothesisWithPose
from cv_bridge import CvBridge
import cv2
import numpy as np
import onnxruntime as ort

class SignDetectorYOLO26(Node):
    def __init__(self):
        super().__init__('sign_detector_yolo26')

        # Parameters
        self.declare_parameter('model_path',
            '~/teamsteelbot_ws/models/signs_yolo26n/weights/best.onnx')
        self.declare_parameter('use_hailo', False)
        self.declare_parameter('confidence_threshold', 0.5)
        self.declare_parameter('iou_threshold', 0.45)

        model_path = self.get_parameter('model_path').value
        self.use_hailo = self.get_parameter('use_hailo').value
        self.conf_threshold = self.get_parameter('confidence_threshold').value
        self.iou_threshold = self.get_parameter('iou_threshold').value

        # Expand path
        import os
        model_path = os.path.expanduser(model_path)

        # Class names
        self.class_names = ['red_sign', 'green_sign', 'blue_sign']

        # Load model
        if self.use_hailo:
            self.load_hailo_model(model_path)
        else:
            self.load_onnx_model(model_path)

        # ROS2 setup
        self.subscription = self.create_subscription(
            Image, '/camera/image_raw', self.image_callback, 10
        )
        self.detection_pub = self.create_publisher(Detection2DArray, '/detections', 10)
        self.debug_pub = self.create_publisher(Image, '/detections/debug_image', 10)

        self.bridge = CvBridge()
        self.frame_count = 0

        self.get_logger().info(f'YOLO26 detector started (Hailo: {self.use_hailo})')

    def load_onnx_model(self, model_path):
        """Load ONNX model for CPU/GPU inference"""
        self.get_logger().info(f'Loading ONNX model: {model_path}')

        # ONNX Runtime session
        providers = ['CUDAExecutionProvider', 'CPUExecutionProvider']
        self.session = ort.InferenceSession(model_path, providers=providers)

        # Get input/output info
        self.input_name = self.session.get_inputs()[0].name
        self.output_names = [out.name for out in self.session.get_outputs()]

        self.input_shape = self.session.get_inputs()[0].shape
        self.input_height = self.input_shape[2]  # 640
        self.input_width = self.input_shape[3]   # 640

        provider = self.session.get_providers()[0]
        self.get_logger().info(
            f'Model loaded: {self.input_width}x{self.input_height} '
            f'(Provider: {provider})'
        )

    def load_hailo_model(self, model_path):
        """Load Hailo HEF model (when supported)"""
        self.get_logger().error(
            'Hailo support for YOLO26 not yet available. '
            'Use use_hailo:=false for ONNX inference, or use YOLO11 for Hailo.'
        )
        raise NotImplementedError("YOLO26 Hailo support coming soon")

    def preprocess_image(self, cv_image):
        """Preprocess image for YOLO26 input"""
        # Resize to model input size
        img = cv2.resize(cv_image, (self.input_width, self.input_height))

        # Convert BGR to RGB
        img = cv2.cvtColor(img, cv2.COLOR_BGR2RGB)

        # Normalize to [0, 1]
        img = img.astype(np.float32) / 255.0

        # Transpose to CHW format (channels first)
        img = img.transpose(2, 0, 1)

        # Add batch dimension
        img = np.expand_dims(img, axis=0)

        return img

    def postprocess_detections(self, outputs, orig_shape):
        """
        Convert YOLO26 outputs to bounding boxes

        YOLO26 has end-to-end architecture, so output format may differ
        from YOLO11. Adjust based on actual model output structure.
        """
        # YOLO26 output is typically: [batch, num_predictions, 4+1+num_classes]
        # [x_center, y_center, width, height, confidence, class_scores...]

        # Get predictions (remove batch dimension)
        predictions = outputs[0]  # Shape: [num_predictions, 4+1+num_classes]

        detections = []

        for pred in predictions:
            # Parse prediction
            if len(pred) < 5:
                continue

            x_center, y_center, w, h = pred[0:4]
            confidence = pred[4]

            # Filter by confidence
            if confidence < self.conf_threshold:
                continue

            # Get class scores (if available)
            if len(pred) > 5:
                class_scores = pred[5:]
                class_id = int(np.argmax(class_scores))
                class_score = class_scores[class_id]

                # Combined score
                score = confidence * class_score
            else:
                # If no class scores, use confidence only
                class_id = 0  # Default class
                score = confidence

            if score < self.conf_threshold:
                continue

            # Convert to pixel coordinates
            orig_h, orig_w = orig_shape[:2]
            x_center_px = x_center * orig_w
            y_center_px = y_center * orig_h
            w_px = w * orig_w
            h_px = h * orig_h

            detections.append({
                'bbox': [x_center_px, y_center_px, w_px, h_px],
                'class_id': int(class_id),
                'class_name': self.class_names[class_id] if class_id < len(self.class_names) else 'unknown',
                'confidence': float(score)
            })

        # YOLO26 is NMS-free, but we can still apply NMS for redundancy
        detections = self.apply_nms(detections)

        return detections

    def apply_nms(self, detections):
        """Apply Non-Maximum Suppression (optional for YOLO26)"""
        if len(detections) == 0:
            return []

        # Convert to format for cv2.dnn.NMSBoxes
        boxes = []
        confidences = []

        for det in detections:
            x_c, y_c, w, h = det['bbox']
            x1 = int(x_c - w / 2)
            y1 = int(y_c - h / 2)
            boxes.append([x1, y1, int(w), int(h)])
            confidences.append(det['confidence'])

        # Apply NMS
        indices = cv2.dnn.NMSBoxes(
            boxes, confidences,
            self.conf_threshold, self.iou_threshold
        )

        # Return filtered detections
        if len(indices) > 0:
            return [detections[i] for i in indices.flatten()]
        else:
            return []

    def image_callback(self, msg):
        """Process incoming image"""
        # Convert ROS Image to OpenCV
        cv_image = self.bridge.imgmsg_to_cv2(msg, desired_encoding='bgr8')
        orig_shape = cv_image.shape

        # Preprocess
        input_tensor = self.preprocess_image(cv_image)

        # Inference
        outputs = self.session.run(self.output_names, {self.input_name: input_tensor})

        # Postprocess
        detections = self.postprocess_detections(outputs, orig_shape)

        # Create ROS2 detection messages
        detection_array = Detection2DArray()
        detection_array.header = msg.header

        debug_image = cv_image.copy()

        for det in detections:
            # Create Detection2D message
            detection = Detection2D()
            detection.header = msg.header

            # Bounding box
            x_c, y_c, w, h = det['bbox']
            detection.bbox.center.position.x = x_c
            detection.bbox.center.position.y = y_c
            detection.bbox.size_x = w
            detection.bbox.size_y = h

            # Classification
            hypothesis = ObjectHypothesisWithPose()
            hypothesis.hypothesis.class_id = det['class_name']
            hypothesis.hypothesis.score = det['confidence']
            detection.results.append(hypothesis)

            detection_array.detections.append(detection)

            # Draw on debug image
            x1 = int(x_c - w / 2)
            y1 = int(y_c - h / 2)
            x2 = int(x_c + w / 2)
            y2 = int(y_c + h / 2)

            color = {
                'red_sign': (0, 0, 255),
                'green_sign': (0, 255, 0),
                'blue_sign': (255, 0, 0),
            }.get(det['class_name'], (255, 255, 255))

            cv2.rectangle(debug_image, (x1, y1), (x2, y2), color, 2)
            cv2.putText(
                debug_image,
                f"{det['class_name']} {det['confidence']:.2f}",
                (x1, y1 - 10),
                cv2.FONT_HERSHEY_SIMPLEX, 0.5, color, 2
            )

        # Publish
        self.detection_pub.publish(detection_array)

        debug_msg = self.bridge.cv2_to_imgmsg(debug_image, encoding='bgr8')
        debug_msg.header = msg.header
        self.debug_pub.publish(debug_msg)

        if detections:
            self.get_logger().info(
                f'Frame {self.frame_count}: Detected {len(detections)} signs',
                throttle_duration_sec=2.0
            )

        self.frame_count += 1

def main(args=None):
    rclpy.init(args=args)
    node = SignDetectorYOLO26()

    try:
        rclpy.spin(node)
    except KeyboardInterrupt:
        pass
    finally:
        node.destroy_node()
        rclpy.shutdown()

if __name__ == '__main__':
    main()
```

### Step 3.2: Update setup.py

```python
# ~/teamsteelbot_ws/src/teamsteelbot_vision/setup.py

from setuptools import setup

package_name = 'teamsteelbot_vision'

setup(
    name=package_name,
    version='0.1.0',
    packages=[package_name],
    data_files=[
        ('share/ament_index/resource_index/packages',
            ['resource/' + package_name]),
        ('share/' + package_name, ['package.xml']),
    ],
    install_requires=['setuptools'],
    zip_safe=True,
    maintainer='Your Name',
    maintainer_email='you@example.com',
    description='Vision detection nodes with YOLO26',
    license='MIT',
    tests_require=['pytest'],
    entry_points={
        'console_scripts': [
            'sign_detector_classic = teamsteelbot_vision.sign_detector_classic:main',
            'sign_detector_yolo26 = teamsteelbot_vision.sign_detector_yolo26:main',
        ],
    },
)
```

### Step 3.3: Build and Test

```bash
# Install dependencies
pip3 install onnxruntime-gpu  # GPU version for laptop
# OR: pip3 install onnxruntime  # CPU version

# Build workspace
cd ~/teamsteelbot_ws
colcon build --packages-select teamsteelbot_vision --symlink-install
source install/setup.bash

# Terminal 1: Mock camera
ros2 run teamsteelbot_simulation mock_camera_node

# Terminal 2: YOLO26 detector
ros2 run teamsteelbot_vision sign_detector_yolo26 --ros-args \
  -p model_path:=~/teamsteelbot_ws/models/signs_yolo26n/weights/best.onnx \
  -p use_hailo:=false \
  -p confidence_threshold:=0.5

# Terminal 3: Monitor detections
ros2 topic hz /detections
ros2 topic echo /detections

# Terminal 4: Visualize in RViz2
rviz2
# Add Image display → /detections/debug_image
```

**Expected performance on laptop:**
- **RTX 4050 (GPU):** 200-300 FPS
- **CPU only:** 30-50 FPS
- **43% faster than YOLO11!**

---

## Phase 4: Deployment to RPi5

### Deployment Options

#### Option 1: YOLO26 with ONNX Runtime (CPU) - Works Now

```bash
# On RPi5
pip3 install onnxruntime

# Transfer model
scp ~/teamsteelbot_ws/models/signs_yolo26n/weights/best.onnx \
    pi@raspberrypi.local:~/teamsteelbot_ws/models/

# Run
ros2 run teamsteelbot_vision sign_detector_yolo26 --ros-args \
  -p model_path:=~/teamsteelbot_ws/models/best.onnx \
  -p use_hailo:=false

# Expected: 15-20 FPS (43% faster than YOLO11 CPU!)
```

#### Option 2: YOLO26 with Hailo - Pending Official Support

```bash
# When Hailo adds YOLO26 support:

# Convert ONNX to HEF
hailomz compile --ckpt best.onnx --hw-arch hailo8l

# Run
ros2 run teamsteelbot_vision sign_detector_yolo26 --ros-args \
  -p model_path:=~/teamsteelbot_ws/models/best.hef \
  -p use_hailo:=true

# Expected: 40-80 FPS (estimate based on 43% speedup)
```

#### Option 3: YOLO11 with Hailo - Proven Fallback

```bash
# Train YOLO11 instead
yolo detect train model=yolo11n.pt data=data.yaml

# Standard Hailo conversion
# See YOLO11 guide for details

# Expected: 30-60 FPS (proven)
```

---

## Performance Comparison

### Laptop (RTX 4050)

| Model | Backend | FPS | Latency | Notes |
|---|---|-----|---|---|
| YOLO26n | ONNX GPU | **250-300** | ~3-4ms | 43% faster! |
| YOLO11n | ONNX GPU | 200-250 | ~4-5ms | Baseline |
| YOLOv8n | ONNX GPU | 180-220 | ~5-6ms | Older |

### Raspberry Pi 5

| Model | Backend | FPS | Latency | Power | Notes |
|---|---|-----|---|---|---|
| **YOLO26n** | **ONNX CPU** | **15-20** | **~60ms** | ~5W | **43% faster!** |
| YOLO11n | ONNX CPU | 10-15 | ~80ms | ~5W | Baseline |
| **YOLO26n** | **Hailo HEF*** | **40-80** | **~15ms** | ~9W | **Estimated** |
| YOLO11n | Hailo HEF | 30-60 | ~20ms | ~9W | Proven |

\* *Pending official Hailo support*

### Key Insights

1. **YOLO26 on CPU is faster than YOLO11 on Hailo** (15-20 vs 30-60 FPS)
   - Use YOLO26 + ONNX CPU if Hailo support isn't ready!

2. **YOLO26 + Hailo should be the fastest combination** (estimated 40-80 FPS)
   - Worth waiting for if you need maximum performance

3. **Fallback strategy works:** YOLO11 + Hailo is proven and competitive

---

## Recommended Development Strategy

### Timeline-Based Approach

```
┌─────────────────────────────────────┐
│  Weeks 1-3: Train YOLO26            │
│  • Best accuracy + speed            │
│  • Develop on laptop (200+ FPS)     │
│  • Build all ROS2 logic             │
└─────────────────────────────────────┘
              ↓
┌─────────────────────────────────────┐
│  Week 4-6: Test & Integrate         │
│  • Full pipeline with YOLO26 ONNX   │
│  • Classical CV fallback            │
│  • TCS34725 validation              │
└─────────────────────────────────────┘
              ↓
┌─────────────────────────────────────┐
│  Week 7: Decision Point             │
│                                     │
│  Check Hailo support:               │
│    ✅ Supported → Deploy YOLO26 HEF │
│    ⏳ Not ready → Choose fallback   │
└─────────────────────────────────────┘
              ↓
     ┌────────┴────────┐
     ↓                 ↓
┌─────────┐      ┌─────────┐
│ Option A│      │ Option B│
│         │      │         │
│ YOLO26  │      │ YOLO11  │
│ on CPU  │      │ + Hailo │
│         │      │         │
│ 15-20   │      │ 30-60   │
│ FPS     │      │ FPS     │
└─────────┘      └─────────┘
     ↓                 ↓
  Both work for competition!
```

### Hybrid Approach (Recommended) 🏆

```python
# In decision_node.py

# Use YOLO26 as primary
if yolo26_confidence > 0.7:
    sign = yolo26_detection

# Classical CV fallback
elif classical_cv_confidence > 0.8:
    sign = classical_cv_detection

# Both agree
elif yolo26_detection == classical_cv_detection:
    sign = yolo26_detection

# Uncertainty
else:
    reduce_speed()
    sign = None

# Physical validation (unique!)
if sign and tcs34725_enabled:
    if not validate_with_color_sensor(sign):
        log_warning("Physical validation failed!")
        sign = None
```

**Benefits:**
- ✅ Best accuracy (YOLO26 + Classical CV voting)
- ✅ Robustness (multiple detection methods)
- ✅ Unique innovation (TCS34725)
- ✅ Works regardless of Hailo support status

---

## Monitoring Hailo Support

### How to Check for YOLO26 Support

```bash
# 1. Check Hailo Model Zoo releases
https://github.com/hailo-ai/hailo_model_zoo/releases

# 2. Monitor Hailo Community Forum
https://community.hailo.ai/

# 3. Check for YOLO26 config files
git pull
ls hailo_model_zoo/cfg/networks/ | grep yolo26

# 4. Check Hailo documentation
https://hailo.ai/developer-zone/documentation/
```

### Expected Timeline

Based on historical patterns:
- **YOLOv8:** Added ~2 months after release
- **YOLO11:** Added ~3 months after release
- **YOLO26:** Expected by **March-April 2026**

---

## Troubleshooting

### Issue: YOLO26 not found

```bash
pip3 install --upgrade ultralytics
yolo version
# Should show 8.3.x or higher
```

### Issue: ONNX output format different

YOLO26's end-to-end architecture may have different output shapes. Check:

```python
# Print output shape
outputs = session.run(None, {input_name: input_tensor})
for i, out in enumerate(outputs):
    print(f"Output {i}: {out.shape}")

# Adjust postprocessing accordingly
```

### Issue: Lower accuracy than expected

```bash
# Train longer
yolo detect train model=yolo26n.pt data=data.yaml epochs=100

# Use larger model
yolo detect train model=yolo26s.pt data=data.yaml epochs=50

# Collect real images (better than synthetic)
```

### Issue: Slow on RPi5 CPU

YOLO26 is 43% faster, but still limited on CPU:

```bash
# Options:
# 1. Wait for Hailo support
# 2. Use YOLO11 + Hailo (proven to work)
# 3. Optimize model further (pruning, quantization)
# 4. Reduce input size (but may hurt accuracy)
```

---

## Summary

### YOLO26 Advantages

✅ **43% faster CPU inference** - Huge for edge devices
✅ **Better accuracy** - 40.9 vs 39.5 mAP
✅ **NMS-free** - Simpler deployment
✅ **Better export** - ONNX/TensorRT optimized
✅ **Edge-first design** - Built for devices like RPi5

### Current Limitations

⏳ **Hailo support pending** - Very new (2 weeks old)
📚 **Less documentation** - Community still catching up
🔧 **May need custom config** - For advanced deployments

### Recommendation

**Start with YOLO26 now!**

1. Train on laptop (RTX 4050)
2. Develop with ONNX Runtime
3. Build complete ROS2 pipeline
4. Monitor Hailo for YOLO26 support
5. Have YOLO11 + Hailo as fallback

**Either way, you'll have a cutting-edge solution! 🚀**

---

## Resources

- [YOLO26 Official Docs](https://docs.ultralytics.com/models/yolo26/)
- [YOLO26 Blog Post](https://blog.roboflow.com/yolo26/)
- [Ultralytics Launch Announcement](https://www.ultralytics.com/blog/meet-ultralytics-yolo26-a-better-faster-smaller-yolo-model)
- [Hailo Model Zoo](https://github.com/hailo-ai/hailo_model_zoo)
- [Hailo Community](https://community.hailo.ai/)
- [YOLO26 Paper (arXiv)](https://arxiv.org/abs/2509.25164)

---

**Next steps:** Start training! 🎯

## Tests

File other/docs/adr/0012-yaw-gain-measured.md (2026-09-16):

# 0012. Yaw gain is a measured fraction of the kinematic model

- Status: superseded by 0086
- Superseded by: 0086
- Date: 2026-08-29
- Commit: bfd644d4

## Context

The fraction of the yaw rate the kinematic model predicts that the chassis
ACTUALLY delivers is 1.0 in the zero-slip textbook model; anything less is the
tyre slip and linkage compliance that model has no term for. Before this was
measured the simulator ran an implicit 1.0 and turned 1.83x sharper than the real
car over the same command stream: 3512 deg of yaw against the IMU's 1918, so every
corner the sim cleared was a corner the hardware would have run wide.

## Options considered

- (a) Keep the implicit 1.0 zero-slip model.
- (b) Measure the delivered yaw and scale the model.

## Decision

(b). `yaw_gain = 0.55`, measured 2026-08-29 from `run_20260829_140424` (a clean
3-lap Open run) via `scripts/bag/diag_bag_sim_fidelity.py --replay`. The shortfall
is flat (~0.49) from 5 to 30 deg of commanded wheel angle, which is what makes it
a scale factor rather than large-angle saturation.

## Consequences

- Sim yaw matches the hardware over the same command stream.
- It is a property of THESE tyres on THIS surface: re-measure after a tyre, weight
  or mat change, the same way `max_speed_mps` is re-measured after a motor swap.

## Superseded by 0086

Replaced by [0086](0086-simulator-realism.md): The simulator runs on a measured error
budget, not a perfect world.

The successor carries the current decision and its rationale; this file keeps
the original decision above so the supersede chain stays readable.

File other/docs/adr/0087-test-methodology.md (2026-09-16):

# 0087. Testing uses a four-level ladder and a fixed A/B protocol

- Status: accepted
- Date: 2026-09-15

## Context

The most expensive mistakes were not programming errors but unverified
assumptions. Fixtures misled repeatedly, a corpus pinned one start cell, and a
simulator that did not model contact, sensing or the servo was trusted to approve
control-law changes.

## Options considered

- (a) Trust the simulator and fixtures.
- (b) A four-level ladder with an explicit rule that a level-2 conclusion is not a
      conclusion, a fixed-seed corpus, and a fixed A/B protocol.

## Decision

(b). The ladder is: level 1 unit tests (95 Python files, 162 Go files) for broken
logic and contracts; level 2 sim corpus for navigation behaviour over hundreds of
tracks; level 3 hardware bench for what the sim does not model (servo, motor, real
LIDAR); level 4 track rounds for the truth. A conclusion that exists only at level
2 is not a conclusion; the simulator discards fast and compares, it does not
approve.

The corpus is fixed-seed (`task gen:corpus:all` = 640 Open and 256 Obstacles, seed
2026), and the same revision on the same corpus gives the same number. Open
screening uses `balanced128`, which varies the start cell rather than pinning
`start_cell = 0` as the old `open128` did; `open128` overstated the shipped config
by about six cases and hid one fix while inflating another. Never quote an Open
figure without its corpus AND seed: the baseline swings nine points from start-cell
assignment alone.

The full metric set is read together: laps>=3, in-time, timeouts, collisions, and
(wrong-side passes on Obstacles, scored against ground truth). `SimResult.success`
is degenerate on Obstacles because it requires `parked`, which is false in 256 of
256; split by collision, not by success. Never read a config value from a literal;
load `load_default()` and print it, and count invocations at the real call site
before an A/B. Never validate a label against the function that derives it; use
independent ground truth. Do not compare sweeps across invocations if concurrent
edits occurred.

The A/B protocol has five named traps: screen with 128, decide with 640; the
reference is the parent commit, not an earlier measurement; results are not
comparable across time; both arms must run identical test modules; prove the two
arms differ before believing the result. `--tuning` replaces the config tree, it
does not merge. Changes that break comparability carry `!` in the commit type.

## Consequences

- The simulator cannot approve a change on its own.
- A measurement without commit, corpus, seed and profile is meaningless.
- CI being red and ignored is worse than no CI.

## History

- 06b7fc1a 2026-08-01: let the chassis graze a wall instead of freezing; every
  pass rate before it needs re-measuring.
- 7b4a50d6 2026-08-01: score the 180 s round limit as a pass criterion.
- 54f326c1, 3b04fcc5 2026-08-22: model and generate the full 640 Open space.
- 551b7f9a 2026-08-30: vary the start cell by default (`balanced128`).
- 59fbcaee 2026-09-04: port the balanced128 screening corpus to Go with a
  reimplemented CPython `random`.
- 3b6456d5, b982e109 2026-09-13: config schemas, `config:check`, and `x-journal`
  rationale links.
- d7e24594 2026-09-14: document the testing workflow and the `!` convention in
  `tests.md` and `CHANGELOG.md`.
- 2026-09-01: the suite pin moved from the retired Injora 14 kg build to the
  Hiwonder 270 deg + REV HD Hex.

## Cross-references

- 0086 owns the fidelity changes the `!` convention marks; 0069 owns the config
  `config:check` that closes the documentation loop.

## Evidence

- Go tests: fuzz the serial frame decoders, use `testing/synctest` for the
  watchdog, and run an in-process NATS (no Docker) behind `//go:build integration`;
  bag-replay and sim-corpus parity are the go/no-go gates.
- `contact_dist = 0.05` can only be settled end-to-end (scan to tick to PID to
  decel) and has no env override; sweep arms are set by editing `clearance.toml`.
- Pytest runs via `pixi run -e dev test` plain, never bare `pytest` (which loses
  the RMW pin and causes false failures). `-n 6 --dist loadscope` is the confirmed
  cap; `-n 12` re-dispatches a dead worker and is slower.
- Parallelise all test and sim sweeps by default (5.6x on 24 cases) and never pipe
  a long run through `tail`.
- Windows is a first-class constraint: pin `RMW_IMPLEMENTATION=rmw_cyclonedds_cpp`
  on win-64 pytest tasks, cap xdist at 6, and do not assume dependency, Docker or
  subprocess parity.
- On the retired motor (`max_speed_mps` 0.156) a 3-lap in-time round was
  arithmetically impossible: about 27 m over three laps needs about 173 s against
  the 180 s round limit. The pin re-baseline cleared 31 failures (21 sim
  solvability, 10 deviation recovery), all only on `SimResult.success ==
  over_time`, none a navigation defect, and the affected runs recovered from the
  pose kick in about 184 steps and completed their laps.
- The recovery envelope is worst narrow/clockwise: about 0.115 m lateral and about
  35 degrees heading.
- The speed-ceiling table over the 8 narrow starts (3 laps against 180 s):
  0.156 m/s gives 0/8 (200.0 s), 0.170 gives 0/8 (194.8 s), 0.185 gives 8/8
  (179.8 s), and 0.234 gives 8/8 (140.8 s).
- The 3-lap path is 26.07 m, so the limit needs a 0.145 m/s average; the 0.156
  ceiling is 7 percent above it and the car sustains about 79 percent of its
  ceiling with corners priced in.
- A servo-only swap is indistinguishable from the slower build (0/8, 200.0 s),
  identical scenario for scenario over the 128-sweep.
- A sim case costs about 39 s of wall clock on a 16-core machine with 15 cores
  idle, the source of the parallel harness's 5.6x on 24 cases.
- The historical Open pass-rate chain of 96, 125 and 126 was all measured on the
  single pinned `start_cell = 0` spawn that `balanced128` replaced.
- `laps>=3` vs `clean` reads 82 and 76 on the 256 corpus at
  `OBSTACLES_CONTACT_DIST` 0.05, so six runs of the headline were disqualified by
  the rule they were counted under.
- Two `diag_sign_sweep.py` overrides silently measured the default instead of the
  swept value (a `lateral_offset` zero-arg factory and an `OBSTACLES_CONTACT_DIST`
  shadowing); prove the arm reaches the navigator before believing a flat sweep.

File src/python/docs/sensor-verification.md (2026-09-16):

# Sensor / Actuator Wiring Reference

What is physically wired where: each sensor and actuator, its board, its bus or pin,
and the ROS topic it lands on. The verification order, the bugs that were found, and
the validation methods are not repeated here.

Rationale lives in the ADRs: `adr:0082-wiring-harness-as-code` (the harness is defined
as code), `adr:0080-lidar-mount-and-scan-plane` (LIDAR mount and scan plane),
`adr:0069-config-governance` (TOML values and schemas). The full netlist is
`schemes/wiring/tscircuit/harness.netlist.txt`, rendered to
`schemes/wiring/harness.schematic.svg` / `.png`; motor-specific wiring is in
`src/python/docs/bts7960-ibt2-wiring.md` and `adr:0076-drivetrain-and-steering-hardware`.

## Devices and topics

| Device | Board | Interface | ROS topic(s) | Notes |
|---|---|---|---|---|
| Slamtec RPLIDAR C1 | Pi 5 | USB via the bundled Slamtec adapter | `/scan` | `/dev/ttyUSB0`, 460800 baud, Standard mode; mounted inverted |
| BNO08x IMU | Pi 5 | MCP2221A USB to UART bridge | `/imu/data` | `/dev/ttyACM0`, 115200 baud, 100 Hz |
| Camera Module 3 Wide | Pi 5 | CSI | `/camera/image_raw`, `/vision/detections` | |
| Hailo-8 AI HAT+ 26 TOPS | Pi 5 | 26-pin header | `/vision/detections` | no `/hailo/fps` topic is published |
| Push button | Pi Zero | GPIO4 | `/button/event`, `/button/hold` | |
| SSD1306 OLED | Pi Zero | I2C1 (SDA1/SCL1), address 0x3C | `/ui/oled_mirror`, `/ui/telemetry_summary` | |
| Challenge-mode jumper | Pi Zero | GPIO23 | `/challenge_mode/jumper_inserted`, `/challenge_mode/active` | |
| Steering servo (Hiwonder HPS-3527SG) | Pi Zero | GPIO12, hardware PWM0 | `/motor/steering_position` | |
| Drive motor (REV HD Hex 6000rpm) + encoder | Pi Zero | BTS7960/IBT-2, quadrature encoder | `/motor/drive_speed`, `/motor/status` | see pin table |
| Pi Zero to Pi 5 link | both | USB gadget (`usb0`, `192.168.250.1`) | cross-board ROS2 graph | |
| Battery / power switch | both | 3S LiPo, switch SW1 | - | see power rails |

## Pi Zero GPIO map

| Pin | Signal |
|---|---|
| GPIO4 | Button signal |
| GPIO5 | BTS7960 `L_EN` (held permanently HIGH) |
| GPIO6 | BTS7960 `R_EN` (held permanently HIGH) |
| GPIO12 | Servo signal (hardware PWM0) |
| GPIO13 | BTS7960 `RPWM`, forward (hardware PWM1) |
| GPIO16 | Motor encoder A |
| GPIO20 | Motor encoder B |
| GPIO23 | Challenge-mode jumper signal |
| GPIO26 | BTS7960 `LPWM`, reverse (software PWM) |
| SDA1 / SCL1 | OLED I2C |

## Pi 5 connections

| Port | Device |
|---|---|
| USB (Zero) | Pi Zero USB-gadget link |
| USB | RPLIDAR C1 via the Slamtec adapter |
| USB | MCP2221A IMU bridge |
| CSI | Camera Module 3 Wide |
| 26-pin header | Hailo-8 AI HAT+ |

## Power rails

| Rail | Source | Load |
|---|---|---|
| Battery | Ovonic 3S LiPo 11.1V | switch SW1 |
| 5V / 5A | KL89576 DCDC | Pi 5 (USB-C power) |
| 5V (Pi USB) | Pi 5 USB | Pi Zero, BTS7960 `VCC`, level-shifter HV |
| 3V3 | Pi Zero 3V3 | level-shifter LV, OLED `VCC`, motor encoder `ENC_VCC` |
| Servo rail | Mini-560 Pro regulator | servo `VCC` |
| Drive rail | battery via SW1 | BTS7960 `B+` |

## Operational notes

- The LIDAR is mounted inverted (`lidar.inverted = true`); the mount facts and the
  angle correction are owned by `adr:0080-lidar-mount-and-scan-plane`.
- Self-occlusion from the robot's own chassis reads as small clusters concentrated
  around the rear, measured spanning about +117 to +172 deg on one side and -122 to
  -177 deg on the other. Mask the whole rearward extent with margin
  (`abs(angle) > 115 deg`) rather than masking each cluster, since the elements are
  thin (wiring, brackets, screw heads) and clip differently on a re-scan.

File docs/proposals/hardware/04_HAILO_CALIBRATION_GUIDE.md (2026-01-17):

# Hailo Model Calibration & GPU Optimization Guide

**Last Updated:** 2026-01-17

This document explains how to calibrate and optimize models for your **Hailo AI HAT+ 26 TOPS** accelerator using GPU acceleration, based on the latest Hailo documentation and community resources.

---

## 🎯 What is Model Calibration?

**Calibration** is the process of converting a trained floating-point model (FP32) to an optimized integer model (INT8) that runs efficiently on the Hailo accelerator.

### Why Calibration is Needed

- **Speed:** INT8 models run 4× faster than FP32
- **Memory:** INT8 models use 4× less memory
- **Power:** Lower precision = lower power consumption
- **Hailo Requirement:** Hailo accelerators run INT8 models exclusively

### The Process

```
Trained Model (FP32, PyTorch/TensorFlow)
    ↓
Export to ONNX (FP32)
    ↓
Hailo Dataflow Compiler
    ├── Parse (understand model structure)
    ├── Optimize (graph optimizations)
    ├── **Quantize (FP32 → INT8)** ← CALIBRATION HAPPENS HERE
    └── Compile (generate HEF file)
    ↓
Hailo HEF (INT8, runs on AI HAT+)
```

---

## 🖥️ GPU Requirements for Calibration

### Recommended Hardware

Based on Hailo documentation and community feedback:

| Component | Minimum | Recommended | Optimal |
|---|---|---|---|
| **GPU** | NVIDIA CUDA-capable | NVIDIA RTX 3060+ | NVIDIA RTX 4090 |
| **RAM** | 16 GB | **32 GB** ⭐ | 64 GB |
| **Storage** | 50 GB free | 100 GB SSD | 500 GB NVMe |
| **OS** | Ubuntu 20.04+ | Ubuntu 22.04 | Ubuntu 24.04 |

**⚠️ IMPORTANT:** It is **strongly recommended** to run calibration on a **GPU machine** with at least **32 GB RAM**.

**Why GPU matters:**
- Calibration processes 1000+ images
- Each image passes through the model
- GPU accelerates this 10-50× vs CPU
- Larger batch sizes = better quantization accuracy

**Native vs Docker:**
- **Native installation** (recommended) - Better GPU access, more reliable
- **Docker** - Works but may have GPU passthrough issues

---

## 📊 Calibration Dataset Requirements

### Dataset Size

**Minimum:** 100 images (for quick testing)
**Recommended:** **1,000+ images** ⭐
**Optimal:** 5,000-10,000 images

From Hailo documentation:
> "The quantization phase requires several hundreds to thousands of data samples, ideally a subset from the training data."

### Dataset Quality

**What you need:**
- ✅ Representative samples from your use case (WRO track images)
- ✅ Diverse conditions (lighting, angles, distances)
- ✅ **Images ONLY** (no annotations/labels required!)
- ✅ Same resolution as training (e.g., 640×640 for YOLO)

**What to include for WRO:**
- Different track configurations
- Various sign positions (left, right, center)
- Lighting variations (bright, dim, shadows)
- Camera angles (straight, tilted)
- Motion blur (simulated or real)

**Example dataset structure:**
```
calibration_data/
├── track_run_001/
│   ├── frame_0001.jpg
│   ├── frame_0002.jpg
│   └── ...
├── track_run_002/
│   └── ...
└── track_run_010/
    └── ...

Total: 1,000-5,000 images
```

### How to Collect Calibration Data

**Option 1: Manual Driving**
```bash
# Record images while driving robot manually
ros2 bag record /camera/image_raw

# Extract images from bag
ros2 bag play recorded_bag.db3 &
python extract_images.py --output calibration_data/
```

**Option 2: Simulation (Gazebo)**
```python
# Generate diverse images in Gazebo
for i in range(1000):
    # Randomize robot position, lighting
    randomize_world()

    # Capture image
    img = capture_camera()
    cv2.imwrite(f'calibration_data/sim_{i:04d}.jpg', img)
```

**Option 3: Combine Real + Synthetic**
- 70% real images (manual driving)
- 30% synthetic (Gazebo with domain randomization)
- **Total: 1,000-2,000 images**

---

## 🔧 Hailo Dataflow Compiler Setup

### Installation (Ubuntu 22.04)

```bash
# Install Hailo Dataflow Compiler
# Download from: https://hailo.ai/developer-zone/

# Example (check latest version):
wget https://hailo.ai/downloads/hailo_dataflow_compiler_3.27.0.tar.gz
tar -xzf hailo_dataflow_compiler_3.27.0.tar.gz
cd hailo_dataflow_compiler_3.27.0

# Install (native - recommended)
sudo ./install.sh

# Verify installation
hailo -v
```

### GPU Setup (CUDA)

```bash
# Install NVIDIA drivers
sudo ubuntu-drivers autoinstall

# Install CUDA Toolkit (version compatible with your GPU)
wget https://developer.download.nvidia.com/compute/cuda/repos/ubuntu2204/x86_64/cuda-keyring_1.0-1_all.deb
sudo dpkg -i cuda-keyring_1.0-1_all.deb
sudo apt-get update
sudo apt-get install cuda

# Verify GPU
nvidia-smi  # Should show your GPU

# Verify CUDA
nvcc --version
```

### Python Environment

```bash
# Create virtual environment
python3 -m venv hailo_env
source hailo_env/bin/activate

# Install dependencies
pip install --upgrade pip
pip install hailo_sdk_client
pip install onnx
pip install opencv-python
pip install numpy
```

---

## ⚙️ Calibration Process

### Step 1: Prepare Your Model

Export your trained model to ONNX:

```python
# Example: Export YOLOv8 to ONNX
from ultralytics import YOLO

model = YOLO('traffic_signs.pt')  # Your trained model
model.export(format='onnx', imgsz=640, simplify=True)
# Outputs: traffic_signs.onnx
```

### Step 2: Create Calibration Configuration

Create `calibration_config.yaml`:

```yaml
# Hailo Model Zoo configuration
# Based on: https://github.com/hailo-ai/hailo_model_zoo

model_name: yolov8n_traffic_signs
input_shape: [1, 3, 640, 640]

# Calibration dataset
calib_set:
  path: /path/to/calibration_data/
  num_calib_batches: 128  # 128 batches × 8 images = 1024 images
  batch_size: 8  # Adjust based on GPU memory

# Quantization settings
quantization:
  precision: int8
  calib_method: mse  # Options: mse, percentile, max
  per_channel: true

# Optimization (optional)
optimization:
  adaround: true  # Better quantization (slower, needs GPU)
  bias_correction: true
```

**Batch Size Guidelines:**
- **8** (default) - For GPUs with 8+ GB VRAM (RTX 3060+)
- **4** - For GPUs with 4-6 GB VRAM (GTX 1660)
- **2** - Minimum (slower but works on smaller GPUs)

From Hailo docs:
> "It is best to use the maximum batch size supported by your GPU for each model to maintain quantization accuracy."

### Step 3: Run Calibration

```bash
# Activate environment
source hailo_env/bin/activate

# Run Hailo Dataflow Compiler
hailo parser onnx \
    --onnx traffic_signs.onnx \
    --hw-arch hailo8l  # Or hailo8 for AI HAT+
    # Output: traffic_signs.har

hailo optimize \
    --har traffic_signs.har \
    --calib-data-path /path/to/calibration_data/ \
    --calib-set-size 1024 \
    --batch-size 8 \
    # Output: traffic_signs_optimized.har

hailo compiler \
    --har traffic_signs_optimized.har \
    --hw-arch hailo8l \
    # Output: traffic_signs.hef (READY FOR DEPLOYMENT!)
```

**Expected Time (GPU):**
- Parsing: ~1 minute
- Optimization/Quantization: **5-30 minutes** (depends on model size, dataset size)
- Compilation: ~5 minutes
- **Total: 10-40 minutes** with GPU

**Expected Time (CPU only):**
- Optimization: **2-6 hours** (10-50× slower!)

### Step 4: Verify Quantized Model

```python
# Test HEF file accuracy
from hailo_platform import HailoScheduler, InferModel

# Load model
model = InferModel('/path/to/traffic_signs.hef')

# Test on validation set
for img_path in validation_images:
    img = preprocess(cv2.imread(img_path))
    output = model.run(img)
    # Compare with original ONNX model output

# Measure accuracy drop (should be <2%)
print(f"Original accuracy: {original_acc}%")
print(f"Quantized accuracy: {quantized_acc}%")
print(f"Accuracy drop: {original_acc - quantized_acc}%")
```

**Acceptable accuracy drop:** <2%
**Good quantization:** <1% accuracy drop

If accuracy drop is >2%, you may need:
- More calibration images (increase from 1k → 5k)
- Better calibration method (try `percentile` instead of `mse`)
- Enable advanced optimizations (`adaround`, `bias_correction`)

---

## 🚀 GPU Acceleration Tips

### 1. Use Maximum Batch Size

```yaml
# Start high, reduce if OOM (out of memory)
batch_size: 16  # Try first
batch_size: 8   # If OOM, reduce to 8
batch_size: 4   # If still OOM, reduce to 4
```

Monitor GPU memory:
```bash
watch -n 1 nvidia-smi  # Watch GPU usage in real-time
```

### 2. Enable NVIDIA DALI (Optional)

For even faster calibration:

```bash
# Install NVIDIA DALI
pip install nvidia-dali-cuda120  # Match your CUDA version

# Enable in Hailo config
# Add to calibration_config.yaml:
use_dali: true
```

**Benefits:**
- 2-3× faster data loading
- GPU-accelerated preprocessing

### 3. Use Native Installation (Not Docker)

From community feedback:
> "Native installation provides better GPU access and is generally more reliable."

**Docker issues:**
- GPU passthrough can fail
- Lower performance
- Complex setup

**Solution:** Install Hailo tools natively on Ubuntu.

---

## 📁 Full Workflow Example: YOLOv8 for WRO

### Step-by-Step

```bash
# 1. Train YOLOv8 (on desktop GPU)
cd ~/wro_ws
python train_yolo.py --data wro_signs.yaml --epochs 100

# 2. Export to ONNX
python export_onnx.py --model runs/train/weights/best.pt

# 3. Collect calibration data
ros2 bag record /camera/image_raw  # Drive manually 10 laps
python extract_images.py --bag recorded.db3 --output calib_data/
# Result: 1,200 images in calib_data/

# 4. Run Hailo calibration (GPU machine)
hailo parse onnx best.onnx --hw-arch hailo8l --har best.har

hailo optimize \
    --har best.har \
    --calib-data-path calib_data/ \
    --calib-set-size 1024 \
    --batch-size 8 \
    --har best_optimized.har

hailo compile --har best_optimized.har --hef best.hef

# 5. Deploy to Raspberry Pi AI HAT+
scp best.hef pi@raspberrypi:/home/pi/wro_ws/models/

# 6. Test on Pi5
ssh pi@raspberrypi
cd ~/wro_ws
python test_hailo.py --model models/best.hef
```

**Total time:** ~2-4 hours (including data collection)

---

## 🔍 Troubleshooting

### Issue 1: "Out of Memory" during calibration

**Symptoms:**
```
RuntimeError: CUDA out of memory
```

**Solutions:**
1. Reduce batch size: `batch_size: 8` → `batch_size: 4`
2. Use fewer calibration images: `calib_set_size: 1024` → `calib_set_size: 512`
3. Close other GPU applications
4. Use a GPU with more VRAM (8GB+ recommended)

### Issue 2: Large accuracy drop (>5%)

**Symptoms:**
Quantized model has much worse accuracy than original.

**Solutions:**
1. **Increase calibration data:** 1k → 5k images
2. **Try different calibration method:**
   ```yaml
   calib_method: percentile  # Instead of mse
   ```
3. **Enable advanced optimizations:**
   ```yaml
   optimization:
     adaround: true
     bias_correction: true
   ```
4. **Check data quality:** Ensure calibration data is representative

### Issue 3: GPU not detected

**Symptoms:**
```
No GPU available, using CPU
```

**Solutions:**
```bash
# Check NVIDIA driver
nvidia-smi

# Install CUDA
sudo apt install nvidia-cuda-toolkit

# Verify PyTorch sees GPU
python -c "import torch; print(torch.cuda.is_available())"
```

### Issue 4: Hailo Compiler errors

**Common errors:**
- `Unsupported ONNX opset` → Update ONNX export: `opset_version=11`
- `Dynamic shapes not supported` → Fix input shape: `imgsz=640` (static)
- `Unsupported layer` → Simplify model: `simplify=True` in export

**Check Hailo logs:**
```bash
cat ~/.hailo/logs/latest.log
```

---

## 📊 Performance Benchmarks

### Expected Performance on Your Hardware

**Your setup:** Raspberry Pi 5 16GB + **Hailo AI HAT+ 26 TOPS**

| Model | Input Size | Hailo FPS | Accuracy | Latency |
|---|---|---|---|---|
| **YOLOv8-Nano** | 640×640 | 40-60 FPS | ~94% | 16-25 ms |
| **YOLOv5s** | 640×640 | 30-45 FPS | ~95% | 22-33 ms |
| **YOLOv8-Small** | 640×640 | 25-35 FPS | ~96% | 28-40 ms |
| **ViT-Small** | 224×224 | 25-35 FPS | ~93% | 28-40 ms |

**Notes:**
- AI HAT+ 26 TOPS is 2× better than Hailo-8L (13 TOPS)
- You'll get upper end of FPS ranges!

---

## 🎯 Recommendations for Your Project

### For Proposal 4 (ROS2 + YOLO) - RECOMMENDED

**Calibration Plan:**

1. **Collect Data (Week 5):**
   - Manual driving: 10 laps → ~1,200 images
   - Gazebo simulation: 500 synthetic images
   - **Total: 1,700 images**

2. **Train YOLO (Week 5):**
   - YOLOv8-Nano on desktop GPU
   - 100 epochs (~2 hours on RTX 3060)

3. **Calibrate with Hailo (Week 6):**
   - Use desktop GPU (RTX 3060+)
   - Batch size: 8
   - Expected time: 20-30 minutes
   - Expected accuracy: ~94%

4. **Deploy (Week 6):**
   - Transfer HEF to Pi5
   - Test: Should get 40-60 FPS!

**GPU Requirements:**
- **Training:** RTX 3060+ (6GB+ VRAM)
- **Calibration:** Same GPU (32GB RAM recommended)

### For Proposal 3 (Vision Transformer)

**Calibration Plan:**

1. **Collect Data (Weeks 3-5):**
   - Manual driving: 50+ hours → ~180,000 images (training)
   - Use subset for calibration: 5,000 images

2. **Train ViT (Weeks 6-8):**
   - PyTorch on desktop GPU
   - 1M RL steps in Gazebo (~3 days)

3. **Calibrate with Hailo (Week 9):**
   - Use desktop GPU
   - Batch size: 4-8 (ViT is larger)
   - Expected time: 45-60 minutes
   - Expected accuracy: ~92-93%

4. **Deploy (Week 9):**
   - Transfer HEF to Pi5
   - Test: Should get 25-35 FPS

**GPU Requirements:**
- **Training:** RTX 4080+ (16GB+ VRAM for ViT training)
- **Calibration:** RTX 3060+ (8GB+ VRAM, 32GB RAM)

---

## 📚 Resources

### Official Documentation
- [Hailo Dataflow Compiler User Guide (v3.27.0)](https://mmmsk.ai.kr/Projects/Embedded-AI/files/hailo_dataflow_compiler_v3.27.0_user_guide.pdf)
- [Hailo Model Zoo (GitHub)](https://github.com/hailo-ai/hailo_model_zoo)
- [Hailo Community Forum](https://community.hailo.ai/)

### Tutorials
- [Convert ONNX Models to Hailo8L: Step-by-Step Guide](https://www.ridgerun.ai/post/convert-onnx-model-to-hailo8l)
- [YOLOv11n to Hailo-8 HEF Compilation Guide](https://common.rosecityrobotics.com/YOLO_ObjectDetection/YOLOv11n_to_Hailo8_Guide.html)
- [Accelerating MediaPipe models with Hailo-8](https://medium.com/@grouby177/accelerating-the-mediapipe-models-with-hailo-8-69dc24719c9f)

### Community Discussions
- [Hailo Calibration - Quantization process](https://community.hailo.ai/t/hailo-calibration-quantization-process/2152)
- [GPU trained model compile error](https://community.hailo.ai/t/gpu-trained-model-compile-error/13625)

---

## ✅ Calibration Checklist

Before deploying to Pi5:

- [ ] Desktop/laptop with NVIDIA GPU (8GB+ VRAM)
- [ ] 32 GB+ RAM
- [ ] Ubuntu 22.04+ installed
- [ ] CUDA and NVIDIA drivers installed
- [ ] Hailo Dataflow Compiler installed (native, not Docker)
- [ ] Collected 1,000+ calibration images
- [ ] Trained model exported to ONNX
- [ ] Calibration config created
- [ ] Ran calibration (hailo optimize)
- [ ] Compiled to HEF (hailo compile)
- [ ] Verified accuracy drop <2%
- [ ] Tested HEF on Pi5 + AI HAT+
- [ ] Measured FPS (should be 30-60 for YOLO)

---

## 🏁 Summary

**Key Takeaways:**

1. **Use GPU for calibration** - 10-50× faster than CPU
2. **Recommended:** NVIDIA RTX 3060+ with 32GB RAM
3. **Calibration dataset:** 1,000-5,000 images (no labels needed)
4. **Expected time:** 10-40 minutes with GPU (vs 2-6 hours CPU)
5. **Accuracy drop:** Should be <1-2%
6. **Your AI HAT+ 26 TOPS:** Excellent hardware! Will run YOLO at 40-60 FPS

**Next Steps:**

1. Set up desktop GPU machine (Ubuntu + CUDA)
2. Install Hailo Dataflow Compiler (native)
3. Collect calibration data (1k+ images)
4. Train & export model to ONNX
5. Calibrate with GPU
6. Deploy HEF to Pi5 + AI HAT+
7. Enjoy fast AI inference! 🚀

---

**Good luck with your Hailo calibration!**

## Sources

- [Hailo Calibration - Quantization process - Hailo Community](https://community.hailo.ai/t/hailo-calibration-quantization-process/2152)
- [Hailo Model Zoo - Optimization Docs](https://github.com/hailo-ai/hailo_model_zoo/blob/master/docs/OPTIMIZATION.rst)
- [Convert ONNX Models to Hailo8L - RidgeRun](https://www.ridgerun.ai/post/convert-onnx-model-to-hailo8l)
- [YOLOv11n to Hailo-8 HEF Compilation Guide - Rose City Robotics](https://common.rosecityrobotics.com/YOLO_ObjectDetection/YOLOv11n_to_Hailo8_Guide.html)
- [Hailo Dataflow Compiler User Guide v3.27.0](https://mmmsk.ai.kr/Projects/Embedded-AI/files/hailo_dataflow_compiler_v3.27.0_user_guide.pdf)
- [Raspberry Pi AI HAT+ 2 announcement - CNX Software](https://www.cnx-software.com/2026/01/15/raspberry-pi-ai-hat-2-targets-generative-ai-llm-vlm-with-hailo-10h-accelerator/)

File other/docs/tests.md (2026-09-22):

# Flujo de pruebas de vTitan

Este documento describe **cómo probamos**, no qué pruebas existen. La lista de
pruebas se lee en el código; lo que no se lee en el código es el criterio: qué
nivel usamos para cada pregunta, qué medimos, y qué trampas nos han costado
conclusiones falsas.

El principio que ordena todo lo demás: **medir antes de optimizar**. Los errores
más caros del proyecto no fueron de programación sino de suposiciones sin
verificar (ver [Hallazgos de ingeniería](README.md#hallazgos-de-ingeniería)), y
cada nivel de esta escalera existe para atrapar una clase distinta de esas
suposiciones.

## Los cuatro niveles

| Nivel | Qué atrapa | Coste por intento | Cuándo se usa |
|---|---|---|---|
| 1. Pruebas unitarias | Lógica rota, contratos de módulo, regresiones | segundos | En cada cambio |
| 2. Corpus de simulación | Comportamiento de navegación sobre cientos de pistas | minutos | Antes de aceptar cualquier ajuste |
| 3. Banco de hardware | Lo que el simulador no modela: servo, motor, LIDAR real | minutos, con el robot delante | Antes de llevar algo a pista |
| 4. Rondas en pista | La verdad | ~3 minutos por ronda, y no se repite a voluntad | Validación final |

La regla que los une: **una conclusión que solo existe en el nivel 2 no es una
conclusión**. El simulador sirve para descartar rápido y para comparar, no para
aprobar.

## Nivel 1: pruebas unitarias

95 archivos de prueba en Python y 162 en Go.

```bash
task test                      # Python + Go, todos los módulos
task robot:test                # solo el robot (entorno pixi)
task robot:test SCOPE=unit     # unit | fast | navigation | hardware | all
task go:test                   # módulo Go del robot (Go puro, sin la ruta CGo de cámara)
task sim:test                  # pruebas de la simulación
task lint                      # ruff, golangci-lint, ESLint, buf lint
```

**Configuración que importa** (`src/python/pytest.ini`):

- `-n 6 --dist loadscope`. Es el máximo confirmado que completa una corrida
  entera. Por encima, los trabajadores nativos de xdist se caen en Windows al
  destruir el contexto de rclpy. No es un número arbitrario y no conviene
  subirlo sin volver a medirlo.
- `-p no:launch_testing -p no:launch_ros`. Los paquetes ROS2 de RoboStack traen
  plugins de pytest cuyos *hookspecs* son incompatibles con pytest >= 8 y
  abortan la recolección. Este proyecto usa pytest plano con simulacros, así que
  se desactivan.
- Marcadores: `hardware` (exige una Raspberry con periféricos) y `slow`
  (simulación de lazo cerrado, varios segundos por caso).

**Trampa conocida:** el conjunto necesita `VTITAN_HARDWARE_PROFILE` **sin
definir**, mientras que los diagnósticos la necesitan **definida**. Una variable
de entorno heredada de una sesión de diagnóstico hace fallar pruebas que no
tienen nada roto.

## Nivel 2: el corpus de simulación

Probar solo en la pista física tiene un límite duro: cada intento cuesta
minutos, cada montaje es distinto, y una situación difícil no se repite a
voluntad. Por eso generamos un corpus con semilla fija.

```bash
task gen:corpus:all            # 640 escenarios Open + 256 Obstacles, semilla 2026
task sim:navigate              # lazo cerrado con el navegador real
task sim:navigate:visualize:all -- --challenge open --interactive   # en vivo, con RViz
```

Semilla fija significa **resultados repetibles**: la misma revisión sobre el
mismo corpus da el mismo número, así que una diferencia entre dos corridas es
una diferencia de código y no de suerte.

### Métricas que decidimos

No usamos "se ve mejor". Cada comparación se resuelve con las mismas columnas:

- **vueltas >= 3**: escenarios donde el robot completó las tres vueltas.
- **en tiempo**: de los anteriores, cuántos dentro del límite de 180 s.
- **tiempos agotados**: escenarios que agotaron el reloj.
- **colisiones**: contactos con pared o con señal.
- **paso por el lado incorrecto** (solo Obstacles): se puntúa contra verdad de
  campo, no contra lo que el robot creía. Un paso por el lado incorrecto
  **termina la ronda**, así que esta columna no se promedia con las demás.

### Protocolo de comparación A/B, y sus cinco trampas

Este protocolo nació de conclusiones que resultaron falsas. Cada punto es una
que nos costó tiempo:

1. **Criba con 128, decide con 640.** 128 escenarios sirven para descartar; no
   sirven para aceptar. Varias recomendaciones sobrevivieron a 128 y murieron al
   volver a medirlas sobre el corpus grande.
2. **La referencia es el commit padre**, no una medición anterior. Medir contra
   un número apuntado la semana pasada compara dos cosas que ya no comparten
   código.
3. **Los resultados no son comparables en el tiempo.** Si el corpus, el modelo
   del simulador o cualquier constante cambiaron entre dos corridas, los dos
   números no se restan.
4. **Las dos ramas deben correr módulos de prueba idénticos.** Un conjunto
   distinto convierte la comparación en ruido.
5. **Diferenciar las dos ramas antes de creer el resultado.** Un eje de barrido
   cableado a la nada produce dos brazos byte a byte idénticos y un veredicto
   perfectamente convincente.

Regla derivada: `--tuning` **reemplaza** el árbol de configuración por el
archivo indicado, no lo superpone. Un A/B que pasa solo la clave que cambia deja
todas las demás en su valor por defecto, y entonces no está midiendo lo que cree.

## Nivel 3: banco de hardware

El simulador no modela todo, y lo que no modela es justamente lo que rompe en
pista. Dos ejemplos medidos: el modelo de contacto del simulador **nunca desliza
a lo largo de una pared**, y el LIDAR simulado es mucho más limpio que el C1
real. Por eso hay pruebas que solo existen contra el robot.

```bash
task go:hw:build                # compila cruzado las pruebas //go:build hw para linux/arm64
task go:hw:build:interactive    # las que mueven el robot: giro de motor, barrido de servo
task go:hw:run                 # compila, envía a la Pi y ejecuta un paquete completo
task robot:test-motors         # prueba de humo del nodo de motores, se corre EN la Pi 5
task robot:calibrate-encoder   # calibración de counts_per_rev contra distancia medida con cinta
```

Las interactivas están **cerradas por operador**: no arrancan solas, porque
mueven el robot. Antes de correrlas hay que parar los servicios de producción
con `task go:hw:stop`, o dos procesos se pelean por el mismo puerto serie.

`robot:calibrate-encoder` merece mención aparte: es la prueba que descubrió que
el encoder daba **60 pulsos por vuelta y no 86**, un error que falseaba toda
medición de distancia y velocidad del proyecto.

## Nivel 4: rondas en pista, y la grabación

Cada ronda queda grabada entera en un bag MCAP: pose, LIDAR, detecciones,
comandos y el estado interno del navegador, tick a tick. Una ronda dura 180 s y
no se repite, así que lo que no quedó grabado se perdió.

```bash
task robot:deploy              # código + detector HEF a la Pi, reconstruye y reinicia servicios
task robot:pull-runs           # baja los bags MCAP
task robot:watch-vision        # detecciones en vivo, una línea por fotograma
```

El análisis posterior vive en los diagnósticos `diag_bag_*.py`. El flujo normal
es empezar por el inventario (una fila por bag) y solo entonces abrir el bag
concreto que interesa.

**Trampas de análisis, todas medidas:**

- **Un diagnóstico que se cae devuelve código de salida 0.** Hay que leer la
  salida, nunca el código. Y para afirmar que algo *no aparece*, hace falta un
  control con algo que sí esté presente; si no, no se distingue un hecho de una
  ruta mal escrita.
- `travelled_m` es **con signo** y se cancela solo cuando el robot oscila
  adelante y atrás. Un robot atascado en un vaivén reporta cero recorrido.
- `/motor/drive_speed` está en **grados por segundo**, no en metros por segundo.
- La longitud del camino calculada desde la pose **sobreestima ~10%**.
- La Pi poda los bags a 20 corridas o 4 GB. El archivo histórico vive en el
  computador de desarrollo, y no debe copiarse de vuelta a la placa.

## Configuración: pruebas que no son de código

El robot está gobernado por un árbol de TOML, y esa configuración se valida como
si fuera código:

```bash
task config:validate    # el árbol src/config/ contra su estructura
task config:lint        # los TOML contra su esquema JSON, con Taplo
task config:check       # cada clave descrita, y cada referencia x-journal resuelve
```

`config:check` es el que cierra el círculo documental: **falla si un valor del
robot cita un ADR que no existe**. Una constante sin justificación rastreable no
pasa la verificación del repositorio.

## Integración continua

`.github/workflows/ci.yml` corre diez trabajos en cada push y en cada pull
request: lint más pruebas del robot, backend Go, la API y el servicio de
aprendizaje del auto-anotador, Hailo, el frontend, y construcción de imágenes
Docker con escaneo de vulnerabilidades.

**Estado real, declarado:** CI está en rojo, y por dos causas concretas que
conviene no confundir con pruebas que fallan:

1. Cuatro trabajos de Docker no arrancan porque la acción
   `aquasecurity/trivy-action` está fijada a una versión `0.28.0` que ya no
   existe. Es un problema de fijado de versión, no del proyecto.
2. Tres trabajos mueren en el paso de Ruff (40, 14 y 2 errores de estilo) **antes
   de llegar a ejecutar una sola prueba**.

Es decir: hoy CI no nos dice nada sobre si las pruebas pasan, porque en la mitad
de los trabajos nunca llegan a correr. Lo anotamos aquí en vez de esconderlo,
porque un CI rojo que nadie mira es peor que no tenerlo: da una sensación de
cobertura que no existe. La verificación real de esta temporada se ha hecho en
local con los niveles 1 a 4 descritos arriba.

## Cómo usamos todo esto en un cambio típico

1. Escribir la prueba unitaria que falla (nivel 1).
2. Implementar hasta que pase, y `task lint`.
3. Correr el corpus de criba, 128 escenarios, contra el **commit padre**.
4. Si sobrevive, repetir con el corpus completo de 640.
5. Si toca hardware, banco (nivel 3) antes de pista.
6. Pista, y el bag se guarda.
7. Si el valor cambiado es una constante de configuración, escribir su ADR en
   `other/docs/adr/` y enlazarlo desde el esquema con `x-journal`, o
   `config:check` lo rechaza.

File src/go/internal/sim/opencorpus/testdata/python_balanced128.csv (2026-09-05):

0 | 600 | 600 | 600 | 600 | north | clockwise | 2
0 | 600 | 600 | 600 | 600 | north | counterclockwise | 1
0 | 600 | 600 | 600 | 600 | south | clockwise | 1
0 | 600 | 600 | 600 | 600 | south | counterclockwise | 3
0 | 600 | 600 | 600 | 600 | east | clockwise | 3
0 | 600 | 600 | 600 | 600 | east | counterclockwise | 3
0 | 600 | 600 | 600 | 600 | west | clockwise | 1
0 | 600 | 600 | 600 | 600 | west | counterclockwise | 2
0 | 600 | 600 | 600 | 1000 | north | clockwise | 1
0 | 600 | 600 | 600 | 1000 | north | counterclockwise | 2
0 | 600 | 600 | 600 | 1000 | south | clockwise | 1
0 | 600 | 600 | 600 | 1000 | south | counterclockwise | 0
0 | 600 | 600 | 600 | 1000 | east | clockwise | 0
0 | 600 | 600 | 600 | 1000 | east | counterclockwise | 0
0 | 600 | 600 | 600 | 1000 | west | clockwise | 2
0 | 600 | 600 | 600 | 1000 | west | counterclockwise | 0
0 | 600 | 600 | 1000 | 600 | north | clockwise | 0
0 | 600 | 600 | 1000 | 600 | north | counterclockwise | 3
0 | 600 | 600 | 1000 | 600 | south | clockwise | 0
0 | 600 | 600 | 1000 | 600 | south | counterclockwise | 0
0 | 600 | 600 | 1000 | 600 | east | clockwise | 4
0 | 600 | 600 | 1000 | 600 | east | counterclockwise | 1
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

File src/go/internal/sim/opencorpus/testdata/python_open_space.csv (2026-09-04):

0 | clockwise | 600 | 600 | 600 | 600 | south | 0 | open_0000[south/cw] | 1.250000 | 0.303000 | 3.141593
1 | clockwise | 600 | 600 | 600 | 600 | south | 1 | open_0001[south/cw] | 1.750000 | 0.303000 | 3.141593
2 | clockwise | 600 | 600 | 600 | 600 | south | 2 | open_0002[south/cw] | 1.250000 | 0.497000 | 3.141593
3 | clockwise | 600 | 600 | 600 | 600 | south | 3 | open_0003[south/cw] | 1.750000 | 0.497000 | 3.141593
4 | clockwise | 600 | 600 | 600 | 600 | north | 0 | open_0004[north/cw] | 1.250000 | 2.697000 | 0.000000
5 | clockwise | 600 | 600 | 600 | 600 | north | 1 | open_0005[north/cw] | 1.750000 | 2.697000 | 0.000000
6 | clockwise | 600 | 600 | 600 | 600 | north | 2 | open_0006[north/cw] | 1.250000 | 2.503000 | 0.000000
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

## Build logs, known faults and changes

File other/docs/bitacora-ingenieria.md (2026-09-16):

# Bitácora de Ingeniería - vTitan, WRO Future Engineers 2026

Esta bitácora recoge las decisiones de ingeniería de vTitan tal como se tomaron: qué nos
obligó a decidir, qué alternativas teníamos, qué elegimos y qué midió el cambio. Está
construida sobre el historial real del proyecto, los commits y las notas que fuimos dejando
mientras desarrollábamos, en vez de reconstruida de memoria al final.

Cada entrada sigue la misma plantilla: contexto o restricción, opciones consideradas, qué
hicimos, el motivo, resultado medido y la referencia al commit o a la nota donde vive el
detalle. Cuando el motivo ya está registrado como decisión, la entrada enlaza con el ADR
correspondiente en `other/docs/adr/` en lugar de repetir el razonamiento. Varias entradas
registran hallazgos incómodos -mediciones que refutaron una hipótesis nuestra, o riesgos que
siguen abiertos- porque son parte del proceso tanto como los aciertos.

Las cinco secciones siguen los criterios de evaluación del reglamento. Como muchas decisiones
son transversales, cada entrada lleva además una línea **Categorías**, y el índice siguiente
agrupa las mismas entradas por tema técnico para quien quiera leer "todo lo del motor" o
"todo lo del LIDAR" de corrido.

---

## Índice por categoría

Un fallo del puente H, por ejemplo, es a la vez hardware eléctrico y una decisión de
seguridad, y aparece bajo ambas etiquetas.

| Categoría | Entradas |
|---|---|
| `motor` | Cambio de motor de tracción (2026-08-27) · `counts_per_rev` es 60 (2026-08-29) · Techo de velocidad 0.58 m/s (2026-08-30) |
| `puente-h` / `eléctrico` | Puente H recableado + fallo del servo (2026-08-27→28) · GPIO flotante, tres capas (2026-08) · PWM compartido → RPWM/LPWM independientes · Pull-down `LPWM` pendiente (riesgo abierto) |
| `mecánica` / `dirección` | Giro a tope de dirección irreal (2026-08-27) · `MAX_STEERING_RATE` sin medir (2026-09-02) · Puente H recableado + fallo del servo (2026-08-27→28) |
| `sensores` / `lidar` | Recalibración de holgura por el desplazamiento del LIDAR (2026-08-22) · Montaje invertido necesita espejo (2026-08-31) · Indicador de localización invertido (2026-08-22) |
| `sensores` / `cámara` | Cámara montada invertida (fecha no registrada) |
| `calibración` | Cambio de motor (2026-08-27) · `counts_per_rev` (2026-08-29) · Techo de velocidad (2026-08-30) · Holgura del LIDAR (2026-08-22) |
| `software-navegación` / `obstáculos` | Dos bay-exits por modelo de contacto (2026-09-02) · Escape no avanza a ciegas (2026-08-28) · Pass-side es seguimiento, no enrutado (2026-09-01) · `OBSTACLES_CONTACT_DIST` (2026-08-31) · Corredor de escape degenerado (2026-09-02) · Escalera de Open (2026-09-02) |
| `parking` / `reglamento` | Modelo de contacto por defecto elegido por reglamento (2026-09-03) · Dos bay-exits (2026-09-02) |
| `arquitectura` / `software` | Perfiles de hardware por componente (2026-08-21) · Montaje invertido LIDAR (2026-08-31) · Migración a Go/NATS (en curso) |
| `decisión-sistema` | Cambio de motor (2026-08-27) · Modelo de contacto por reglamento (2026-09-03) · `OBSTACLES_CONTACT_DIST` (2026-08-31) · Dos bay-exits (2026-09-02) · Migración a Go/NATS |
| `riesgo-abierto` | `MAX_STEERING_RATE` sin medir (2026-09-02) · Pass-side, convención bajo sospecha (2026-09-03) · Pull-down `LPWM` pendiente |
| `metodología` / `pruebas` | Barridos no comparables entre corridas concurrentes (2026-09-03) |
| `seguridad` | GPIO flotante del puente H, tres capas (2026-08) · Pull-down `LPWM` pendiente |

---

## 1. Mobility and Mechanical Design

### [2026-08-27] El giro a tope de la dirección es físicamente irreal en simulación

**Categorías:** `mecánica` `dirección` `simulación`

**Contexto/restricción:** el simulador permitía radios de giro de dirección extremos
(virtualmente hasta ~8 mm de radio de giro), muy por debajo de lo que un servo Ackermann real
puede lograr.

**Opciones consideradas:** (a) seguir tuneando el software de navegación contra ese límite de
simulación tal cual, o (b) medir el ángulo de rueda real del chasis y limitar el modelo al
valor físico.

**Qué hicimos:** medimos el ángulo de giro máximo real del chasis y lo usamos como límite
duro tanto en simulación como en el controlador.

**Motivo (ADR):** `adr:0076-drivetrain-and-steering-hardware`.

**Resultado medido:** el límite de dirección pasó a estar acotado por la medición física del
chasis, no por el valor por defecto del simulador.

**Referencia:** nota interna `sim_full_lock_steering_is_unphysical_2026_08_27`.

---

### [2026-09-02] El `MAX_STEERING_RATE` de software es una suposición, no una medición

**Categorías:** `mecánica` `dirección` `riesgo-abierto`

**Contexto/restricción:** el limitador de velocidad de giro de la dirección (que actúa tanto
como limitador de software como parámetro de rampa en simulación) estaba fijado en 1.2
rad/s, un valor asumido, no medido en el servo real (~35 kg·cm).

**Opciones consideradas:** dejarlo como estaba (arriesgando que el ajuste del zigzag ("weave")
en simulación esté ajustado a un actuador más rápido de lo real) vs. medirlo en banco.

**Qué hicimos:** documentamos explícitamente que el valor es no medido y que probablemente el
servo real ronda ~5 rad/s; quedó marcado como pendiente de banco de pruebas antes de seguir
tuneando el comportamiento de zigzag ("weave") con ese parámetro.

**Motivo (ADR):** `adr:0076-drivetrain-and-steering-hardware`.

**Resultado medido:** N/A todavía - pendiente de medición en banco. Se documenta como riesgo
abierto, no como hallazgo cerrado (ver también sección 4, pensamiento sistémico).

**Referencia:** nota interna `max_steering_rate_is_unmeasured_2026_09_02`.

---

### [2026-08-29] `counts_per_rev` real del encoder es 60, no 86

**Categorías:** `motor` `calibración`

**Contexto/restricción:** todo el modelo de velocidad (feedforward, tope de velocidad,
odometría) dependía de la constante de cuentas por revolución del encoder, que estaba fijada
en 86 sin verificación en hardware.

**Opciones consideradas:** confiar en el valor de datasheet/estimado (86) o medirlo
directamente en el robot físico.

**Qué hicimos:** medimos en vivo y confirmamos 60 cuentas/rev.

**Motivo (ADR):** `adr:0076-drivetrain-and-steering-hardware` (la calibración no se hereda).

**Resultado medido:** corrección propagada a feedforward (`drive_feedforward_is_affine`) y al
tope de velocidad real del chasis (ver siguiente entrada).

**Referencia:** nota interna `encoder_counts_per_rev_is_60_not_86_2026_08_29`.

---

### [2026-08-30] El techo de velocidad real es ~0.58 m/s, no ~0.45 m/s

**Categorías:** `motor` `calibración`

**Contexto/restricción:** tras corregir `counts_per_rev`, el "techo" de velocidad de 0.45 m/s
que se usaba como referencia quedó identificado como un artefacto de la constante de encoder
vieja, no como un límite físico real del chasis.

**Qué hicimos:** re-caracterizamos la curva duty→rpm con la constante corregida y
recalculamos el techo real: ~0.58 m/s a `max_duty=0.5`, hasta ~0.9 m/s en lazo abierto a
máximo duty.

**Motivo (ADR):** `adr:0085-speed-envelope`.

**Resultado medido:** techo actualizado a 0.58 m/s; también se corrigió un límite de
velocidad del localizador (`max_speed_mps`) que congelaba silenciosamente la pose por encima
de 0.25 m/s, muy por debajo del nuevo techo real (subido a 0.60 m/s).

**Referencia:** `drive_ceiling_058_supersedes_045_2026_08_30`,
`localizer_speed_gate_froze_pose_2026_08_29`. Commit relacionado:
`654e57e6 fix(config): max_speed_mps is the measured 0.58, not the feel-based 1.0`.

---

### [2026-08-27] Cambio de motor de tracción y por qué obligó a recalibrar todo el lazo de control

**Categorías:** `motor` `calibración` `decisión-sistema`

**Contexto/restricción:** se reemplazó el motor de tracción original por un motor nuevo (REV
HD Hex). El motor retirado había sido caracterizado en banco el 2026-07-25
(`counts_per_rev`/`max_rpm` del encoder, ganancias PID), y esa caracterización quedó
obsoleta de golpe con el cambio físico.

**Opciones consideradas:** (a) mantener la caracterización vieja y solo ajustar ganancias a
ojo hasta que "se sintiera bien", o (b) tratar el cambio de motor como un evento que invalida
toda la cadena de calibración aguas abajo y volver a medir desde cero.

**Qué hicimos:** lo primero fue contener el riesgo. Limitamos el ciclo de trabajo en lazo
cerrado a un techo del 50% (`EncoderConfig.max_duty`), un tope independiente de la calibración
vieja del encoder. Hacía falta porque el motor nuevo midió ~1 m/s en hardware, muy por encima
de lo que podían anticipar tanto la matemática de RPM, basada en el motor retirado, como el
límite `drivetrain.max_speed_mps=0.234`, un valor adivinado que solo alimentaba navegación y
simulación.

Con el robot ya protegido de una sobrevelocidad peligrosa, rehicimos la caracterización
completa. `counts_per_rev` pasó de 676.0 a 86.0 y `max_rpm` de 42.5 a 123.0, derivados de
datos de banco: velocidades comandadas sostenidas, medidas con cinta métrica, con el valor
objetivo y el medido convergiendo en estado estable, adelante y en reversa, con un acuerdo
dentro del ~3%.

Las ganancias PID (`pid_kp`/`pid_ki`) se reescalaron en el mismo factor, ~7.9x redondeado a 8.
Bajar `counts_per_rev` vuelve la lectura de RPM mucho más sensible por unidad de movimiento
real de la rueda, y las ganancias viejas, dimensionadas para la escala menos sensible,
producían una oscilación visible en cuanto se aplicaba la corrección.

**Motivo (ADR):** `adr:0076-drivetrain-and-steering-hardware` (calibración nunca heredada; el
tope de duty como contención previa).

**Resultado medido:** la nueva caracterización quedó marcada explícitamente como
**provisional** (derivada de temporización, no de conteos crudos) hasta reverificarla con
`scripts/hardware/calibrate_encoder.py`; el reescalado de ganancias PID también quedó
marcado como **no verificado en vivo** en esa misma sesión (batería desconectada antes de
poder probarlo). Se agregó un registro de depuración por cada paso de PID
(`target_rpm`/`measured_rpm`/`duty`) específicamente para poder *ver* la oscilación en vez de
inferirla de síntomas externos - esa instrumentación fue lo que hizo visible tanto la
oscilación nueva como la saturación cerca de `max_duty` que tenía la calibración vieja.

**Resultado final (nota de mantenimiento):** una sesión posterior (2026-08-29) volvió a medir
y encontró que el valor real de `counts_per_rev` es 60, no 86 - es decir, incluso esta
recalibración "post motor nuevo" quedó superada por una medición más precisa (ver entrada
anterior). Se documenta ambas para dejar clara la cadena completa: motor viejo (676/42.5) →
motor nuevo, primera recalibración por temporización (86/123, provisional) → medición directa
en vivo (60 cpr, confirmada). Es un buen ejemplo de **iteración honesta**: cada paso se marcó
con su nivel real de confianza en vez de presentarse como definitivo.

**Referencia:** commits `a30fe05c`/`51c9f914 fix(robot): cap closed-loop drive duty at 50%
after motor swap`, `fe07b2cf`/`4f254ef4 fix(robot): recalibrate encoder for new drive motor,
add PID-step debug log`, `bbd6803f feat(hardware): raise the speed ladder for the REV HD Hex
motor`. Ver también `encoder_counts_per_rev_is_60_not_86_2026_08_29` y
`motor_servo_bench_session_2026_08_28`.

---

### [2026-08-27→28] El puente H se recableó y el firmware de calibración de servo tenía un fallo en los nombres de carpeta

**Categorías:** `puente-h` `eléctrico` `servo` `mecánica`

**Contexto/restricción:** junto con el cambio de motor, el puente H (BTS7960) se recableó
físicamente, lo que invirtió el sentido eléctrico esperado de la señal `drive.reversed`
(commits `8e83945c`/`8fccb633 fix(robot): flip drive.reversed for the BTS7960 rewire`) - un
recordatorio de que un cambio de cableado físico también es una entrada que debe
propagarse al software, no solo un detalle de electrónica.

**Qué hicimos (fallo del servo, hallado por separado):** se descubrió que la capa de
configuración para el servo de dirección (`range_deg=270`, para el servo Hiwonder de 35 kg
realmente instalado) nunca se había aplicado en hardware. La función que carga las capas por
nombre de perfil (`_profile_overlay_paths()`) construye la ruta a partir del nombre de
`VTITAN_HARDWARE_PROFILE` y **si la carpeta no existe, la omite en silencio, sin error ni
señal**. La carpeta estaba nombrada `servo270`, que nunca coincidió con el nombre real del
perfil activo (`270deg-hiwonder-35kg`) - así que cada comando de servo estuvo usando
matemática de ancho de pulso para un servo de **180°**, en un servo físico de **270°**, desde
que se instaló.

**Por qué importa:** este es un cambio de comportamiento real una vez desplegado, no solo una
corrección cosmética - el mismo ángulo comandado ahora mapea a un swing de ancho de pulso
distinto (ej. 67.5° pasa de 2250 µs a 2000 µs), así que la dirección se siente **menos
agresiva por grado** en ángulos intermedios que antes. Se documentó explícitamente como algo
que requiere reverificación en hardware, no solo confiar en la corrección de código.
`adr:0070-hardware-profiles-and-challenge-overlays`.

**Resultado medido:** corrección de nombre de carpeta aplicada; además se corrigieron
referencias obsoletas a "servo270" en docs, Taskfile y texto de ayuda del generador Go, y un
error en la comparacion de servos que indicaba reiniciar el servicio
equivocado
(`vtitan-pi5.service` en vez de que `ackermann_motor_node` corre en el Pi Zero).

**Referencia:** commit `3a7d7cbe fix(robot): rename servo270 profile folder to match active
profile name`.

### Lo que falta de mecánica

Nos falta material gráfico. Hace falta un diagrama dimensionado del chasis (30 × 19.4 cm,
1.3 kg) y de la disposición de las ruedas (7 cm de diámetro), tomando `robot.toml` como fuente
de verdad para las cotas. Hacen falta también fotos o el CAD de la dirección Ackermann que
fabricamos, y conviene decir de forma explícita que **no** es el chasis LEGO Bugatti Bolide,
porque a simple vista se parecen y la diferencia es justo lo que fabricamos nosotros.

Queda pendiente además escribir la sesión de banco de motor y servo del 28 de agosto como una
iteración con datos de antes y después de la retonificación del PID. Esa entrada debe incluir
la reverificación en vivo del reescalado de ganancias, que sigue sin hacerse.

---

## 2. Power and Sensor Architecture

### [2026-08-21] Los perfiles de hardware son por componente, no globales

**Categorías:** `arquitectura` `software`

**Contexto/restricción:** el sistema soporta simulación y hardware real, y cada
componente (LIDAR, cámara, motores) necesita saber si está hablando con hardware real o con
un simulador.

**Qué hicimos:** implementamos perfiles de hardware **por componente** en vez de un único
indicador global, y documentamos que un perfil sin activar no tiene efecto aunque el archivo esté
editado.

**Motivo (ADR):** `adr:0070-hardware-profiles-and-challenge-overlays`.

**Resultado medido:** N/A (decisión de arquitectura); efecto colateral documentado: si el
perfil no está seteado, el import falla en vez de fallar en silencio con comportamiento
incorrecto.

**Referencia:** `hardware_profiles_are_per_component_2026_08_21`,
`hardware_profile_not_activated_2026_08_20`.

---

### [2026-08-22] Recalibración de la distancia de giro por el desplazamiento físico del LIDAR

**Categorías:** `sensores` `lidar` `calibración`

**Contexto/restricción:** el LIDAR no está montado en el centro geométrico del chasis, así
que las distancias de holgura para las maniobras de giro medidas "desde el LIDAR" no
coincidían con el espacio real disponible para el chasis.

**Qué hicimos:** recalibramos las distancias de holgura de giro teniendo en cuenta el desplazamiento
físico del sensor respecto al centro del chasis.

**Motivo (ADR):** `adr:0080-lidar-mount-and-scan-plane`.

**Resultado medido:** constante `TURN_CLEARANCE_M` anterior quedó invalidada por el cambio de
calibración.

**Referencia:** `lidar_offset_clearance_recalibration_2026_08_22`.

---

### [2026-08-31] El montaje invertido del LIDAR necesita un espejo, no una rotación de 180°

**Categorías:** `sensores` `lidar` `software`

**Contexto/restricción:** el LIDAR está montado invertido en el chasis. La corrección
"ingenua" para un montaje invertido es sumar 180° al ángulo reportado.

**Opciones consideradas:** corregir con `+180°` (rotación) vs. corregir invirtiendo el eje
angular (espejo).

**Qué hicimos:** identificamos que un montaje invertido requiere **espejar** el ángulo
decodificado, no rotarlo, y corregimos el controlador en la migración a Go
(`2ebe7d7d fix(lidar): mirror decoded angles for an inverted mount, not rotate`).

**Motivo (ADR):** `adr:0080-lidar-mount-and-scan-plane`.

**Resultado medido:** corregido en la implementación Go (`robot-go`); la implementación
Python (`LidarYawOffsetRad()` / `sector.go` / `_LIDAR_YAW_OFFSET_RAD`) quedó identificada como
pendiente de corregir en conjunto para no divergir entre ambas.

**Referencia:** `lidar_inverted_mount_needs_mirror_not_rotation_2026_08_31`.

---

### [2026-08-22] Un indicador de localización por LIDAR estaba invertido en su semántica

**Categorías:** `sensores` `lidar` `software`

**Contexto/restricción:** el indicador `use_lidar_localization` se interpretaba de forma
contraintuitiva: `True` hacía el problema de localización **más difícil**, no más fácil, al
contrario de lo que su nombre sugiere.

**Qué hicimos:** documentamos explícitamente el comportamiento real del indicador para evitar que
futuras pruebas lo usaran con la semántica intuitiva incorrecta.

**Motivo (ADR):** `adr:0084-localizer-divergence-and-relocalization`.

**Referencia:** `use_lidar_localization_reads_backwards_2026_08_22`.

---

### [2026-08] El puente H (BTS7960) mantuvo el motor girando a máxima velocidad en reversa al arrancar - historia de un fallo de seguridad en tres capas

**Categorías:** `puente-h` `eléctrico` `seguridad`

**Contexto/restricción:** el controlador de motor emplea un puente H BTS7960 controlado por GPIO
(habilitación `R_EN`/`L_EN`) y PWM (`RPWM`/`LPWM`). Se descubrió en hardware que, en ciertas
condiciones, el motor arrancaba girando a máxima velocidad en reversa sin que el software de
control hubiera comandado eso - un fallo de seguridad grave, no cosmético.

**Capa 1 - secuenciación de habilitación (`f0fc617b`/`d8791b89`):** se identificó que
`R_EN`/`L_EN` podían quedar en HIGH (habilitados) antes de que los canales PWM estuvieran
confirmados en 0% duty. Se corrigió para que ambos canales PWM se confirmen en 0 antes de
habilitar el puente H - invariante que después se preservó explícitamente al portar el controlador
a Go (`511d0a00`/`01e7cb78`), con pruebas dedicadas
(`TestController_Connect_NeverEnablesBeforeZeroingEitherChannel`,
`TestController_SetSpeed_NeverBothChannelsNonzero`) para que nunca se reintroduzca en
silencio.

**Capa 2 - flotación de GPIO al arrancar (`bd60aa82`/`f5797c6a`):** con la capa 1 corregida,
seguía pasando que el motor giraba a máxima reversa **antes** de que el nodo de control
siquiera arrancara. Se midió en hardware que un pull-down *pasivo* de GPIO
(`gpio=...=pd`) no cierra la ventana de arranque: el propio nivel-shifter del BTS7960 tiene
un pull-up interno de ~10 kΩ por canal, que le gana al pull-down interno del SoC (mucho más
débil, ~50 kΩ). Ese hueco dejaba que el motor de tracción girara a máxima velocidad en
reversa antes de que `connect()` del nodo del motor llegara a ejecutarse. La solución que sí
funcionó, verificada en hardware con el servicio systemd deshabilitado: manejar esos 3 pines
como salida activa forzada a bajo (`gpio=...=op,dl`) desde firmware, confirmando en un
arranque limpio que los pines se mantienen bajos desde el arranque mismo, y que `gpiozero`
los puede seguir reclamando después sin conflicto cuando el servicio arranca.

**Capa 3 - flotación de GPIO al detener el servicio (`a55612b4`/`96020000`):** un
`systemctl stop` normal, o cualquier caída del proceso, libera los descriptores de archivo
GPIO que `gpiozero` retiene para `LPWM`/`R_EN`/`L_EN`. En el momento en que se liberan, el
pull-up del nivel-shifter los vuelve a arrastrar a HIGH. Lo reprodujimos en vivo: motor a
máxima reversa en un `stop` rutinario, no solo en arranque en frío. La corrección de
`config.txt` (`op,dl`) de la capa 2 solo cubre la ventana de arranque, porque es una
instrucción de firmware de una sola vez, no un valor por defecto que se reaplique al liberar
el pin. Usamos
`ExecStopPost` de systemd, que se ejecuta después de que el proceso principal termina por
cualquier razón que systemd conozca, para volver a forzar esos pines a bajo. Eso cierra la
mayor parte del hueco sin tocar el ciclo de vida ni el apagado propios del nodo.

**Por qué importa:** esta cadena de tres capas **no cubre todos los casos**, y lo dejamos
dicho aquí en lugar de darla por cerrada. Una pérdida de energía cruda seguiría dejando los
pines flotando, y la mitigación completa, una resistencia pull-down física en `LPWM`,
**todavía no está instalada**. Es un modo de falla identificado con mitigación parcial y un
riesgo residual que sigue vivo; queda repetido en la sección 4 para que no se pierda.

**Referencia:** `gpio_boot_float_full_speed_motor_2026_08_27`,
`gpio_float_reverse_on_script_to_service_handoff_2026_08_28`,
`bts7960_connect_ordering_bug_2026_08_28`. Commits: `f0fc617b`, `d8791b89`, `bd60aa82`,
`f5797c6a`, `a55612b4`, `96020000`, `9748b30d fix(robot): template the BTS7960 GPIO pins into
the systemd stop-hook`, `873a1232 fix(robot): re-drive BTS7960 GPIO pins low on driver
disconnect`.

---

### [fecha no registrada] El diseño de cableado del puente H cambió de PWM compartido a RPWM/LPWM independientes

**Categorías:** `puente-h` `eléctrico`

**Contexto/restricción:** el diseño original de `driver.py`/`config.py` alimentaba el puente
H con un PWM compartido hacia un demultiplexor externo, en vez de usar las dos señales
`RPWM`/`LPWM` del BTS7960 de forma verdaderamente independiente.

**Qué hicimos:** se migró a señales `RPWM`/`LPWM` independientes (commit `6aee1ac2`), y
posteriormente se detectó que la documentación (`.env.example`, comentarios de
`bts7960.toml`, el docstring de `ackermann_motor_node`, y los tests) seguía describiendo el
diseño viejo de demux compartido y los pines `R_EN`/`L_EN` intercambiados.

**Por qué:** documentación desincronizada del cableado real es peligrosa específicamente en
un componente de seguridad (control de motor) - alguien depurando con la documentación vieja
llegaría a conclusiones incorrectas sobre qué pin hace qué.

**Resultado medido:** confirmado en vivo en hardware (registros del Pi Zero): `forward=13`,
`reverse=26`, `r_en=6`, `l_en=5`, conecta y activa limpiamente con el diseño independiente.

**Referencia:** commit `dcec0b93 docs(robot): catch up BTS7960 env/toml/test docs to
independent RPWM/LPWM`.

---

### [fecha no registrada] La cámara estaba montada invertida y el indicador de software nunca se activó

**Categorías:** `sensores` `cámara` `software`

**Contexto/restricción:** la cámara está físicamente montada boca abajo en el chasis. La
lógica de rotación y volteo para compensar un montaje invertido ya existía en el controlador, pero el
indicador `camera_inverted` estaba en `false` por defecto en ambos TOML de configuración del
controlador.

**Qué hicimos:** activamos `camera_inverted` por defecto.

**Motivo (ADR):** `adr:0078-camera-mount-and-focus`. Nota operativa: el frame sin rotar espejaba
silenciosamente izquierda/derecha, lo que afectaba la detección de pass-side (ver Criterio 3 y 4).

**Resultado medido:** corrección directa del defecto de imagen espejada; efecto colateral
positivo documentado explícitamente en la detección de pass-side.

**Referencia:** commit `78c1692e fix(robot): enable camera_inverted for upside-down camera
mount`.

### Arquitectura de sensores

- **Cómputo:** NPU Hailo-8 para aceleración de inferencia.
- **Cámara:** Raspberry Pi Camera Module 3 Wide, 102° de campo de visión horizontal.
- **LIDAR:** Slamtec C1 (modo *dense*; se identificó y corrigió un mismatch de modo de
  escaneo que producía lecturas de rango erróneas - `lidar_c1_dense_mode_scan_mismatch`).
- **IMU:** BNO085.
- **Chasis:** Ackermann personalizado, no un kit LEGO.

### Lo que falta de potencia y sensores

El hueco más grande de este criterio es el presupuesto de potencia: hoy no lo tenemos
calculado formalmente, solo conocemos el tope de velocidad del tren motriz. Hay que medir el
consumo en pico y en reposo, y desglosarlo por rama sobre un diagrama de cableado real que vaya
de la batería a los reguladores y de ahí a motores y electrónica.

El método de calibración de la cámara y de la IMU sí existe, pero vive disperso en notas de
sesión. Falta consolidarlo en un procedimiento paso a paso que otro equipo pueda seguir.

---

## 3. Software Architecture and Obstacle Strategy

> **⚠️ Salvedad de medición (agregado 2026-09-05):** el commit `ecc3cdef fix(sim): only score a
> sign pass the scorer actually watched happen` corrigió el sistema de puntaje de pass-side -
> antes, ser *colocado* más allá del radio de una señal dentro de 1.20 m contaba como paso por
> el lado incorrecto, aunque el robot nunca hubiera hecho esa aproximación. **Todas las cifras
> de Obstacles citadas en esta sección (y en la sección 4) fueron medidas antes de esa
> corrección y no son directamente comparables con mediciones posteriores.** El efecto conocido
> es que corridas que antes terminaban temprano ahora sobreviven hasta chocar contra algo real:
> las colisiones de control suben de 5 a 14. Antes de citar cualquiera de estos números como
> estado actual, volver a medir con el evaluador corregido.

### [2026-09-02] Dos maniobras de salida de bahía, decididas por el modelo de contacto físico

**Categorías:** `software-navegación` `obstáculos` `parking` `decisión-sistema`

**Contexto/restricción:** existían dos implementaciones candidatas para la maniobra de salida
de la bahía de estacionamiento (el "bay exit"), cada una con éxito casi perfecto (254/256)
bajo *distintos* modelos de contacto de simulación - la que ganaba dependía enteramente de
si el modelo de contacto permite "deslizar" contra la pared o la hace "trincar" (ratchet).

**Opciones consideradas:** (a) `0f277aa1` - salida que fija ("latches") el lado abierto y
mantiene el steering, compatible con un modelo de contacto que trinca; (b) `ae15ee3e` -
salida cíclica de 26°, con steering fijado antes de avanzar, compatible con un modelo de
contacto que desliza.

**Qué hicimos:** enviamos `ae15ee3e` (modelo *slide*) como comportamiento por defecto.

**Motivo (ADR):** `adr:0062-sim-contact-model-and-parking`. Se descartó el modelo
`--solid-walls` (premia el contacto) porque tocar los límites del cajón anula todos los puntos de
parking y el simulador nunca desliza contra paredes.

**Resultado medido:** ambas maniobras llegan a 254/256 en simulación bajo su modelo
respectivo; la decisión de cuál enviar no se tomó por la métrica de simulación (empatada)
sino por cuál corresponde a comportamiento legal según el reglamento.

**Referencia:** `bay_exit_solved_by_hold_steer_2026_09_02`,
`wro_2026_scoring_parking_and_bay_start_2026_09_03`. Commits:
`0f277aa1`, `544958be`, `ae15ee3e feat(nav): ship the cycle bay exit`.

Esta entrada pertenece también al **criterio 4**: la decisión no se tomó por el resultado en
simulación, sino por una restricción externa, el reglamento, que la simulación por sí sola no
podía revelar.

---

### [2026-08-28] La maniobra de escape no debe avanzar hacia una pared que el robot no puede ver

**Categorías:** `software-navegación` `obstáculos` `sensores`

**Contexto/restricción:** la maniobra reactiva de "escape" (usada al detectar contacto o
proximidad de obstáculo) podía comandar avance hacia adelante incluso cuando el cono frontal
del LIDAR no tenía lecturas válidas (retorno nulo), lo cual el software interpretaba
erróneamente como "espacio libre" en lugar de "sensor degradado".

**Qué hicimos:** distinguimos explícitamente "cono sin retorno de LIDAR" (sensor degradado)
de "cono con retorno indicando espacio libre", y bloqueamos el escape hacia adelante en el
primer caso.

**Motivo (ADR):** `adr:0055-escape-maneuver-selection` (falla en cerrado ante un rear no leído).

**Resultado medido:** la corrección llevó la maniobra de 0 a 2 vueltas completadas en la
prueba de referencia usada en ese momento.

**Referencia:** `obstacles_escape_maneuver_forward_into_wall_2026_08_28`,
`obstacles_lidar_no_return_reads_as_clear_2026_08_28`. Commits:
`bda6b10c fix(nav): don't escape FORWARD into a wall the robot cannot see`,
`d638800b fix(nav): an unreadable forward cone is a degraded sensor, not open road`.

---

### [2026-09-01] El error de "pass-side" (lado de paso de señal) es de seguimiento, no de ruteo

**Categorías:** `software-navegación` `obstáculos`

**Contexto/restricción:** el robot ocasionalmente pasaba una señal (poste/obstáculo) por el
lado incorrecto, lo cual en el reglamento WRO no solo vale 0 puntos sino que **termina la
ronda** (regla 9.24.5) - el fallo más caro posible en este desafío.

**Opciones consideradas:** la hipótesis inicial era que el planificador de ruta (el "enrutador")
elegía el lado incorrecto (fallo de decisión o de enrutado). La hipótesis alternativa era que el
enrutador decidía bien pero el controlador de seguimiento de trayectoria no ejecutaba esa
decisión con suficiente margen.

**Qué hicimos:** medimos: el plan de ruta acertaba el lado correcto en 642 de 642 casos, con
un margen de diseño de 5.6 cm - es decir, el enrutador **no** era el problema.

**Motivo (ADR):** `adr:0059-pass-side-travel-relative-and-scorer-independence`.

**Resultado medido:** confirmó y superó una hipótesis anterior ("fallo de enrutado") y otra más
antigua ("puntuado sobre creencia, no verdad de terreno") que ya habían sido corregidas por
separado. Trabajo posterior (`sign_pass_error_is_outward_bias`) encontró que el error
residual es un **sesgo sistemático hacia afuera** (84% de los casos, +7.53 cm vs. 5.6 cm de
margen), no dispersión aleatoria - lo cual implica que es corregible ajustando la puntería
del controlador, no agregando más margen de seguridad.

**Referencia:** `obstacles_pass_side_is_tracking_not_routing_2026_09_01`,
`sign_pass_error_is_outward_bias_not_scatter_2026_09_03`,
`pass_side_is_a_round_ender_and_convention_may_be_wrong_2026_09_03`.

---

### [2026-08-31] `OBSTACLES_CONTACT_DIST` a 0.05: mejora medible, con un costo aceptado

**Categorías:** `software-navegación` `obstáculos` `decisión-sistema`

**Contexto/restricción:** el umbral de distancia de contacto que dispara la maniobra de
escape reactivo (`OBSTACLES_CONTACT_DIST`) estaba en un valor que dejaba muchos casos sin
activar el escape a tiempo.

**Qué hicimos:** movimos el umbral a 0.05 m y medimos el efecto en una corrida de referencia
de 256 casos: vueltas completadas subieron de 68 a 434 (agregado), vueltas-por-run ≥3 subieron
de 11 a 82, y los timeouts bajaron de 126 a 48.

**Motivo (ADR):** `adr:0061-contact-zone-per-challenge` (que documenta también la subida
posterior a 0.07).

**Resultado medido:** mejora neta clara en finalización de vueltas y reducción de timeouts,
**pero** con una regresión aceptada conscientemente: los casos de "pass-side" (el fallo más
caro, ver entrada anterior) empeoraron de 82 a 122. Se documentó explícitamente como
trade-off pendiente de resolver por la vía del seguimiento, no revirtiendo este cambio.

**Referencia:** `obstacles_contact_dist_is_shippable_and_pass_side_is_next_2026_08_31`.
Commit: `1de8094d feat(nav): ship the Obstacles contact zone at 0.05`.

---

### [2026-09-02] El límite del corredor de escape lateral no puede excluir ningún rumbo a distancia de contacto

**Categorías:** `software-navegación` `obstáculos`

**Contexto/restricción:** se investigó si el corredor de escape lateral (la zona angular que
la maniobra de escape considera "segura" para desviarse) podía restringirse geométricamente
para evitar que el escape empujara al robot hacia el lado incorrecto de una señal.

**Qué hicimos:** medimos que, a la distancia de contacto real, el corredor de escape se
degenera - no existe ningún rumbo que el corredor pueda excluir sin también excluir rumbos
necesarios para escapar del obstáculo inmediato. El 82% de los escapes están impulsados por
esta "puerta" geométrica, y el 92% son de tipo lateral.

**Motivo (ADR):** `adr:0055-escape-maneuver-selection`. La solución al pass-side debe venir de la
capa de seguimiento (ver la entrada anterior), no de la capa reactiva.

**Referencia:** `escape_gate_corridor_degenerates_at_contact_range_2026_09_02`,
`lateral_escape_is_load_bearing_2026_09_02` (que además refutó la opción de simplemente
suprimir el escape lateral: hacerlo reduce pass-side de 122 a 80 pero dispara las colisiones
con señales de 4 a 97 - un trade-off mucho peor).

---

### [2026-09-02] Escalera de velocidad de Open elevada a 0.26/0.38/0.50 m/s

**Categorías:** `software-navegación`

**Contexto/restricción:** la escalera de velocidad del desafío Open (velocidades objetivo en
tramos sucesivos) estaba en valores conservadores; había margen de tiempo sin usar si se
pudiera subir sin introducir colisiones.

**Qué hicimos:** elevamos la escalera a 0.26/0.38/0.50 m/s y verificamos 639/640 corridas sin
colisión en el corpus de referencia. Se probó también 0.60 m/s como siguiente escalón.

**Motivo (ADR):** `adr:0085-speed-envelope` (0.60 m/s es un acantilado de colisión).

**Resultado medido:** 639/640 sin colisión con la escalera actual; 0.60 m/s descartado por el
comportamiento de acantilado.

**Referencia:** `open_speed_ladder_raised_to_050_2026_09_02`. Commit:
`a98bcbc4 feat(nav): raise the Open speed ladder, and stop justifying it with a stale lap time`.

---

### Arquitectura del software

- Control de trayectoria por **pure pursuit** (`waypoint_controller`), con un
  navegador central (`core_navigator`) que separa planificación de ruta, seguimiento de
  trayectoria y una capa reactiva de escape ante contacto/proximidad.
- La estrategia de obstáculos emplea un enrutador de "lado de paso" (pass-side) separado del
  controlador de seguimiento - la investigación de este año confirmó que el enrutador es correcto
  y que el error reside en el seguimiento, lo cual cambió el foco del trabajo (ver arriba).
- Migración en curso de partes del software de Python (ROS2/rclpy) a Go (`robot-go`) sobre
  transporte NATS, en fases documentadas.

### Lo que falta de software

La máquina de estados completa, desde el arranque en la bahía hasta el estacionamiento pasando
por Open y Obstacles, solo existe hoy como código y notas dispersas. Falta dibujarla como
diagrama de flujo.

Falta también reunir en un solo lugar las métricas con las que ajustamos: tasa de colisión,
vueltas completadas, error de trayectoria y tasa de paso por el lado correcto. Ahora mismo cada
una se explica dentro de la entrada donde apareció, y no hay un solo sitio donde
consultarlas juntas.

---

## 4. Systems Thinking and Engineering Decisions

### [2026-09-03] El modelo de contacto por defecto se elige por reglamento, no por score de simulación

**Categorías:** `decisión-sistema` `parking` `reglamento`

**Contexto/restricción:** el reglamento oficial WRO 2026 establece que tocar los límites del
cajón de estacionamiento durante el parking **anula todos los puntos de parking**, no solo
resta puntos parciales.

**Qué hicimos:** revisamos todas las estrategias de bay-exit/parking que dependían de
contacto sostenido con la pared para funcionar en simulación (incluyendo una que lograba
254/256 usando `--solid-walls`) y las descalificamos como estrategia válida, aunque su
métrica de simulación fuera excelente. Se fijó el modelo de contacto **por defecto** (no el
de paredes sólidas) como el que se debe usar para cualquier evaluación futura.

**Motivo (ADR):** `adr:0062-sim-contact-model-and-parking`.

**Resultado medido:** N/A (es una decisión de política de ingeniería, no un experimento) -
pero desbloqueó la decisión correcta entre las dos maniobras de bay-exit empatadas en score
(ver Criterio 3, `ae15ee3e` vs. `0f277aa1`).

**Referencia:** `wro_2026_scoring_parking_and_bay_start_2026_09_03`.

---

### [2026-09-03] El "pass-side" es la falla más cara del desafío, y su convención de medición está bajo sospecha

**Categorías:** `decisión-sistema` `riesgo-abierto` `reglamento`

**Contexto/restricción:** el reglamento define el lado de paso correcto **relativo al sentido
de viaje** del robot (rojo a la derecha del sentido de marcha), pero el enrutador y el sistema
de puntaje interno del proyecto lo definen en términos **absolutos**. Ambas convenciones
coinciden en sentido antihorario, pero **difieren en sentido horario** - y la simulación
actual no puede exponer esta diferencia porque no varía el sentido de la pista de forma que
la distinga.

**Qué hicimos:** documentamos el riesgo explícitamente como **no resuelto** y decidimos
**no cambiar la convención unilateralmente** - se marcó como pendiente de confirmar con
criterio humano antes de modificar el enrutador o el evaluador de puntaje, precisamente porque un cambio
incorrecto aquí podría "arreglar" una convención que en realidad estaba bien, y esconder el
problema real.

**Motivo (ADR):** `adr:0059-pass-side-travel-relative-and-scorer-independence` (no cambiar la
convención unilateralmente; pendiente de criterio humano).

**Resultado medido:** riesgo identificado, con nota explícita de "preguntar antes de
cambiar" - ejemplo directo de identificación de riesgo + mitigación por precaución, en vez
de por corrección de código.

**Referencia:** `pass_side_is_a_round_ender_and_convention_may_be_wrong_2026_09_03`.

---

### [2026-09-03] Los resultados de los barridos no son comparables entre sí si hay ediciones concurrentes

**Categorías:** `metodología` `pruebas`

**Contexto/restricción:** el mismo conjunto de pruebas ("arm") dio 21/256 fallos en una
corrida y 5/256 en otra corrida posterior, sin cambios de código propios que lo explicaran.

**Qué hicimos:** investigamos y encontramos que una sesión de desarrollo **concurrente**
estaba editando código de parking/simulación mientras la corrida de referencia se ejecutaba,
contaminando la comparación. Se estableció como regla de proceso: los resultados de un barrido
sólo son comparables **dentro de una misma invocación**, nunca entre corridas separadas en el
tiempo si hubo cambios concurrentes en el repositorio.

**Motivo (ADR):** `adr:0087-test-methodology`.

**Resultado medido:** se adoptó `--strip-parking` como forma de aislar resultados de
obstáculos del ruido introducido por trabajo paralelo en parking.

**Referencia:** `sweep_results_not_comparable_across_time_2026_09_03`.

---

### [en curso, desde ~2026-08] Migrar el software del robot de Python/ROS2 a Go/NATS: una decisión de arquitectura, no una reescritura por gusto

**Categorías:** `arquitectura` `decisión-sistema` `software`

**Contexto/restricción:** el software original se ejecuta sobre Python con ROS2 (rclpy) como
framework de nodos/transporte. El primer commit de esta migración lo describe explícitamente
como el **"reemplazo a largo plazo de ROS2"** (`258f1f9e feat(robot-go): scaffold Go/NATS
workspace for the long-term ROS2 replacement`), no como un experimento paralelo.

**Opciones consideradas:** quedarse en Python/ROS2 e invertir el esfuerzo de mejora en ese
sistema, frente a migrar de forma incremental a Go sobre transporte NATS, nodo por nodo (controladores de
hardware primero: BTS7960, LIDAR, IMU, botón, OLED; luego telemetría y máquina de estados
central), preservando invariantes de seguridad ya verificadas en la implementación Python
(ej. la secuenciación de habilitación del puente H, ver arriba, portada explícitamente con
pruebas dedicadas).

**Qué hicimos:** se ejecutó como migración **por fases**, documentada aparte
(`go_nats_migration_plan`), con cada controlador de hardware portado y re-verificado
individualmente contra el hardware real antes de avanzar (ej. el controlador de LIDAR en modo classic
primero, luego un controlador aparte para el modo Dense cuando se detectó que el modo de escaneo
importaba - ver `lidar_c1_dense_mode_scan_mismatch`). A la fecha de esta entrada, ~99
commits tocan el árbol `robot-go`, cubriendo transporte, controladores de todos los sensores y
actuadores, un supervisor de reinicio con notificación a systemd, y agregación de
telemetría.

**Motivo (ADR):** `adr:0068-go-parallel-track-single-cutover`. Migración incremental por
componente y preservación explícita de las invariantes de seguridad ya ganadas (pruebas dedicadas
al portar el puente H). Sigue pendiente consolidar en un solo documento por qué Go y no
Python/ROS2 (ver el cierre de esta entrada).

**Resultado medido:** migración en curso, no completa (fases documentadas por separado,
casillas de progreso ya desactualizadas respecto al código real - hay que verificar contra
el árbol antes de citar como terminado cualquier fase específica).

**Referencia:** `go_nats_migration_plan`, `go_migration_progress` (a través de Fase 5),
`bts7960_connect_ordering_bug_2026_08_28`. Commit inicial: `258f1f9e`/`43662ee0`.

Falta escribir el razonamiento de **por qué Go y no seguir en Python/ROS2** (rendimiento,
tipado, consumo de recursos en la Pi Zero, concurrencia) como una entrada propia. Hoy vive
implícito en las decisiones de código, y no como la comparación explícita de trade-offs que un
hace falta para juzgar la decisión desde fuera.

---

### [riesgo abierto] El pull-down físico de `LPWM` sigue sin instalarse

**Categorías:** `puente-h` `eléctrico` `riesgo-abierto`

**Contexto/restricción:** la cadena de tres capas de mitigación del fallo de GPIO flotante del
puente H (ver Criterio 2) cierra la ventana de arranque en frío y la ventana de detención de
servicio, pero **no cubre una pérdida de energía cruda** (corte de batería, desconexión
abrupta) - en ese caso los pines vuelven a flotar y el pull-up interno del nivel-shifter
puede volver a llevar el motor a máxima reversa.

**Qué hicimos:** documentamos explícitamente que la mitigación completa (una resistencia
pull-down física soldada en `LPWM`) es conocida, está identificada como la solución que sí
cubre el caso restante, y **todavía no está instalada** físicamente en el robot.

**Por qué se documenta como riesgo y no se cierra en falso:** una mitigación de software de
tres capas se siente "casi completa", y es tentador reportarla como resuelta. Documentar
explícitamente el caso que **no** cubre evita asumir una seguridad
que no existe todavía - especialmente relevante para un componente que puede mover el chasis
a máxima velocidad sin comando del software.

**Referencia:** `gpio_boot_float_full_speed_motor_2026_08_27` (nota: título dice "NOT FULLY
FIXED").

---

### Restricciones del sistema identificadas explícitamente

- **Físicas:** techo de velocidad real 0.58 m/s, radio de giro mínimo real medido en banco,
  chasis 1.3 kg / 30×19.4 cm - todos usados como límites duros del controlador, no solo como
  datos de referencia.
- **De cómputo:** NPU Hailo-8 como aceleración obligatoria para mantener el pipeline de
  visión dentro de presupuesto de tiempo real.
- **De reglamento:** contacto con límites de parking anula puntaje completo (no parcial);
  pass-side termina la ronda - ambas restricciones, no técnicas sino normativas, condicionan
  directamente qué soluciones técnicas son aceptables aunque simulen bien.
- **De fidelidad de simulación:** el modelo de contacto no desliza contra paredes (ver
  Criterio 3) - cualquier ajuste que dependa de ese comportamiento está sobreajustado al
  simulador, no al robot real. Esta es una restricción epistemológica, no física: limita qué
  conclusiones de simulación se pueden confiar sin validación en hardware.
- **De seguridad eléctrica no cerrada del todo:** el fallo de GPIO flotante del puente H (ver
  Criterio 2) está mitigado en software en tres capas, pero el caso de pérdida de energía
  cruda sigue dependiendo de una resistencia física aún no instalada - restricción de
  hardware pendiente, no de software.

---

## 5. Reproducibility and GitHub Quality

El repositorio acumula 1365 commits (medido el 2026-09-09), todos con la convención
`tipo(alcance): mensaje` (`feat(nav):`, `fix(sim):`, `docs(readme):`, `perf(nav):`). El
`README.md` ronda los 110.000 caracteres. Ambas cifras superan con holgura los mínimos
cuantitativos del Apéndice C, aunque
ese no era el objetivo: la convención de commits se adoptó porque el historial es nuestra
primera fuente para reconstruir cuándo y por qué cambió algo, y varias entradas de esta
bitácora se escribieron leyendo `git log`.

La estructura separa el material de competencia en `src/`: `src/python` (el sistema de navegación
en Python/ROS2), `src/go` (la migración en curso), `src/python/shared` (la configuración y el ajuste
que ambos comparten), `src/config` (los TOML que ambos leen) y `src/model` (los JSON Schemas que
describen cada clave y enlazan su justificación con `other/docs/adr/`). A partir de esos esquemas,
`task config:gen` genera los DTOs tipados de Go (`src/go/internal/config/generated/`) y de Python
(`src/python/shared/src/shared/config/generated/`), de modo que la descripción de una constante
tiene un solo lugar y las dos implementaciones no pueden divergir en silencio. Todo lo que no es
material de competencia se movió bajo `other/`, incluida la documentación en `other/docs/` con sus
subcarpetas `adr`, `development`, `internal` y `reference`.
Las dependencias se gestionan con `uv` en Python y con Pixi/RoboStack para ROS2, y las
operaciones habituales están encapsuladas en el `Taskfile` (`task sim:navigate...`,
`task rpi:stack`) para que nadie tenga que reconstruir de memoria un comando largo.

### Lo que falta de reproducibilidad

El historial es continuo pero no está etiquetado: hay que marcar con tags los hitos de
competencia (`v1.0` para el regional, `v2.0` para el final internacional) y acompañarlos de
notas de versión. Falta también un `tests.md` que explique el flujo de pruebas de forma
centralizada, porque hoy está repartido entre notas de sesión.

El CAD y los diagramas de cableado que faltan en los criterios 1 y 2 tienen que acabar
**dentro** del repositorio, no solo referenciados desde él: una documentación que apunta a
archivos que no viaja con ella no es reproducible.

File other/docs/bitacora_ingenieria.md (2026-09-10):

# Bitácora de Ingeniería - V-Titan, WRO Future Engineers 2026

Esta bitácora recoge las decisiones de ingeniería de V-Titan tal como se tomaron: qué nos
obligó a decidir, qué alternativas teníamos, qué elegimos y qué midió el cambio. Está
construida sobre el historial real del proyecto, los commits y las notas que fuimos dejando
mientras desarrollábamos, en vez de reconstruida de memoria al final.

Cada entrada sigue la misma plantilla: contexto o restricción, opciones consideradas, qué
hicimos, por qué, resultado medido y la referencia al commit o a la nota donde vive el
detalle. Varias entradas registran hallazgos incómodos -mediciones que refutaron una
hipótesis nuestra, o riesgos que siguen abiertos- porque son parte del proceso tanto como los
aciertos.

Las cinco secciones siguen los criterios de evaluación del reglamento. Como muchas decisiones
son transversales, cada entrada lleva además una línea **Categorías**, y el índice siguiente
agrupa las mismas entradas por tema técnico para quien quiera leer "todo lo del motor" o
"todo lo del LIDAR" de corrido.

---

## Índice por categoría

Un fallo del puente H, por ejemplo, es a la vez hardware eléctrico y una decisión de
seguridad, y aparece bajo ambas etiquetas.

| Categoría | Entradas |
|---|---|
| `motor` | Cambio de motor de tracción (2026-08-27) · `counts_per_rev` es 60 (2026-08-29) · Techo de velocidad 0.58 m/s (2026-08-30) |
| `puente-h` / `eléctrico` | Puente H recableado + fallo del servo (2026-08-27→28) · GPIO flotante, tres capas (2026-08) · PWM compartido → RPWM/LPWM independientes · Pull-down `LPWM` pendiente (riesgo abierto) |
| `mecánica` / `dirección` | Giro a tope de dirección irreal (2026-08-27) · `MAX_STEERING_RATE` sin medir (2026-09-02) · Puente H recableado + fallo del servo (2026-08-27→28) |
| `sensores` / `lidar` | Recalibración de holgura por el desplazamiento del LIDAR (2026-08-22) · Montaje invertido necesita espejo (2026-08-31) · Indicador de localización invertido (2026-08-22) |
| `sensores` / `cámara` | Cámara montada invertida (fecha no registrada) |
| `calibración` | Cambio de motor (2026-08-27) · `counts_per_rev` (2026-08-29) · Techo de velocidad (2026-08-30) · Holgura del LIDAR (2026-08-22) |
| `software-navegación` / `obstáculos` | Dos bay-exits por modelo de contacto (2026-09-02) · Escape no avanza a ciegas (2026-08-28) · Pass-side es seguimiento, no enrutado (2026-09-01) · `OBSTACLES_CONTACT_DIST` (2026-08-31) · Corredor de escape degenerado (2026-09-02) · Escalera de Open (2026-09-02) |
| `parking` / `reglamento` | Modelo de contacto por defecto elegido por reglamento (2026-09-03) · Dos bay-exits (2026-09-02) |
| `arquitectura` / `software` | Perfiles de hardware por componente (2026-08-21) · Montaje invertido LIDAR (2026-08-31) · Migración a Go/NATS (en curso) |
| `decisión-sistema` | Cambio de motor (2026-08-27) · Modelo de contacto por reglamento (2026-09-03) · `OBSTACLES_CONTACT_DIST` (2026-08-31) · Dos bay-exits (2026-09-02) · Migración a Go/NATS |
| `riesgo-abierto` | `MAX_STEERING_RATE` sin medir (2026-09-02) · Pass-side, convención bajo sospecha (2026-09-03) · Pull-down `LPWM` pendiente |
| `metodología` / `pruebas` | Barridos no comparables entre corridas concurrentes (2026-09-03) |
| `seguridad` | GPIO flotante del puente H, tres capas (2026-08) · Pull-down `LPWM` pendiente |

---

## 1. Mobility and Mechanical Design

### [2026-08-27] El giro a tope de la dirección es físicamente irreal en simulación

**Categorías:** `mecánica` `dirección` `simulación`

**Contexto/restricción:** el simulador permitía radios de giro de dirección extremos
(virtualmente hasta ~8 mm de radio de giro), muy por debajo de lo que un servo Ackermann real
puede lograr.

**Opciones consideradas:** (a) seguir tuneando el software de navegación contra ese límite de
simulación tal cual, o (b) medir el ángulo de rueda real del chasis y limitar el modelo al
valor físico.

**Qué hicimos:** medimos el ángulo de giro máximo real del chasis y lo usamos como límite
duro tanto en simulación como en el controlador.

**Por qué:** cualquier controlador tuneado contra un límite de dirección irreal producirá
comportamiento que no es reproducible en el robot físico - el criterio de "reproducibilidad"
exige que las decisiones de ajuste tengan base física, no solo numérica.

**Resultado medido:** el límite de dirección pasó a estar acotado por la medición física del
chasis, no por el valor por defecto del simulador.

**Referencia:** nota interna `sim_full_lock_steering_is_unphysical_2026_08_27`.

---

### [2026-09-02] El `MAX_STEERING_RATE` de software es una suposición, no una medición

**Categorías:** `mecánica` `dirección` `riesgo-abierto`

**Contexto/restricción:** el limitador de velocidad de giro de la dirección (que actúa tanto
como limitador de software como parámetro de rampa en simulación) estaba fijado en 1.2
rad/s, un valor asumido, no medido en el servo real (~35 kg·cm).

**Opciones consideradas:** dejarlo como estaba (arriesgando que el ajuste del zigzag ("weave")
en simulación esté ajustado a un actuador más rápido de lo real) vs. medirlo en banco.

**Qué hicimos:** documentamos explícitamente que el valor es no medido y que probablemente el
servo real ronda ~5 rad/s; quedó marcado como pendiente de banco de pruebas antes de seguir
tuneando el comportamiento de zigzag ("weave") con ese parámetro.

**Por qué:** el mismo parámetro alimenta dos sistemas (limitador real y física de
simulación); si el valor es incorrecto, cualquier conclusión sobre causas del "weave" en
simulación queda contaminada.

**Resultado medido:** N/A todavía - pendiente de medición en banco. Se documenta como riesgo
abierto, no como hallazgo cerrado (ver también sección 4, pensamiento sistémico).

**Referencia:** nota interna `max_steering_rate_is_unmeasured_2026_09_02`.

---

### [2026-08-29] `counts_per_rev` real del encoder es 60, no 86

**Categorías:** `motor` `calibración`

**Contexto/restricción:** todo el modelo de velocidad (feedforward, tope de velocidad,
odometría) dependía de la constante de cuentas por revolución del encoder, que estaba fijada
en 86 sin verificación en hardware.

**Opciones consideradas:** confiar en el valor de datasheet/estimado (86) o medirlo
directamente en el robot físico.

**Qué hicimos:** medimos en vivo y confirmamos 60 cuentas/rev.

**Por qué:** un valor de encoder incorrecto sesga toda la cadena de control de velocidad -
mejor corregirlo en la fuente que compensarlo aguas abajo con ganancias ad-hoc.

**Resultado medido:** corrección propagada a feedforward (`drive_feedforward_is_affine`) y al
tope de velocidad real del chasis (ver siguiente entrada).

**Referencia:** nota interna `encoder_counts_per_rev_is_60_not_86_2026_08_29`.

---

### [2026-08-30] El techo de velocidad real es ~0.58 m/s, no ~0.45 m/s

**Categorías:** `motor` `calibración`

**Contexto/restricción:** tras corregir `counts_per_rev`, el "techo" de velocidad de 0.45 m/s
que se usaba como referencia quedó identificado como un artefacto de la constante de encoder
vieja, no como un límite físico real del chasis.

**Qué hicimos:** re-caracterizamos la curva duty→rpm con la constante corregida y
recalculamos el techo real: ~0.58 m/s a `max_duty=0.5`, hasta ~0.9 m/s en lazo abierto a
máximo duty.

**Por qué:** usar un techo subestimado deja rendimiento sobre la mesa (velocidad de crucero
más baja de la necesaria) y puede sesgar el ajuste del controlador de velocidad.

**Resultado medido:** techo actualizado a 0.58 m/s; también se corrigió un límite de
velocidad del localizador (`max_speed_mps`) que congelaba silenciosamente la pose por encima
de 0.25 m/s, muy por debajo del nuevo techo real (subido a 0.60 m/s).

**Referencia:** `drive_ceiling_058_supersedes_045_2026_08_30`,
`localizer_speed_gate_froze_pose_2026_08_29`. Commit relacionado:
`654e57e6 fix(config): max_speed_mps is the measured 0.58, not the feel-based 1.0`.

---

### [2026-08-27] Cambio de motor de tracción y por qué obligó a recalibrar todo el lazo de control

**Categorías:** `motor` `calibración` `decisión-sistema`

**Contexto/restricción:** se reemplazó el motor de tracción original por un motor nuevo (REV
HD Hex). El motor retirado había sido caracterizado en banco el 2026-07-25
(`counts_per_rev`/`max_rpm` del encoder, ganancias PID), y esa caracterización quedó
obsoleta de golpe con el cambio físico.

**Opciones consideradas:** (a) mantener la caracterización vieja y solo ajustar ganancias a
ojo hasta que "se sintiera bien", o (b) tratar el cambio de motor como un evento que invalida
toda la cadena de calibración aguas abajo y volver a medir desde cero.

**Qué hicimos:** lo primero fue contener el riesgo. Limitamos el ciclo de trabajo en lazo
cerrado a un techo del 50% (`EncoderConfig.max_duty`), un tope independiente de la calibración
vieja del encoder. Hacía falta porque el motor nuevo midió ~1 m/s en hardware, muy por encima
de lo que podían anticipar tanto la matemática de RPM, basada en el motor retirado, como el
límite `drivetrain.max_speed_mps=0.234`, un valor adivinado que solo alimentaba navegación y
simulación.

Con el robot ya protegido de una sobrevelocidad peligrosa, rehicimos la caracterización
completa. `counts_per_rev` pasó de 676.0 a 86.0 y `max_rpm` de 42.5 a 123.0, derivados de
datos de banco: velocidades comandadas sostenidas, medidas con cinta métrica, con el valor
objetivo y el medido convergiendo en estado estable, adelante y en reversa, con un acuerdo
dentro del ~3%.

Las ganancias PID (`pid_kp`/`pid_ki`) se reescalaron en el mismo factor, ~7.9x redondeado a 8.
Bajar `counts_per_rev` vuelve la lectura de RPM mucho más sensible por unidad de movimiento
real de la rueda, y las ganancias viejas, dimensionadas para la escala menos sensible,
producían una oscilación visible en cuanto se aplicaba la corrección.

**Por qué:** un cambio de motor no es un ajuste de parámetro - invalida silenciosamente cada
constante que dependía de las características físicas del motor anterior (relación
encoder/vuelta, RPM máximo, ganancias de control). Tratar el tope de ciclo de trabajo como medida de
contención *antes* de recalibrar, en vez de recalibrar bajo presión con el robot ya
acelerando fuera de rango, fue la decisión de seguridad correcta.

**Resultado medido:** la nueva caracterización quedó marcada explícitamente como
**provisional** (derivada de temporización, no de conteos crudos) hasta reverificarla con
`scripts/hardware/calibrate_encoder.py`; el reescalado de ganancias PID también quedó
marcado como **no verificado en vivo** en esa misma sesión (batería desconectada antes de
poder probarlo). Se agregó un registro de depuración por cada paso de PID
(`target_rpm`/`measured_rpm`/`duty`) específicamente para poder *ver* la oscilación en vez de
inferirla de síntomas externos - esa instrumentación fue lo que hizo visible tanto la
oscilación nueva como la saturación cerca de `max_duty` que tenía la calibración vieja.

**Resultado final (nota de mantenimiento):** una sesión posterior (2026-08-29) volvió a medir
y encontró que el valor real de `counts_per_rev` es 60, no 86 - es decir, incluso esta
recalibración "post motor nuevo" quedó superada por una medición más precisa (ver entrada
anterior). Se documenta ambas para dejar clara la cadena completa: motor viejo (676/42.5) →
motor nuevo, primera recalibración por temporización (86/123, provisional) → medición directa
en vivo (60 cpr, confirmada). Es un buen ejemplo de **iteración honesta**: cada paso se marcó
con su nivel real de confianza en vez de presentarse como definitivo.

**Referencia:** commits `a30fe05c`/`51c9f914 fix(robot): cap closed-loop drive duty at 50%
after motor swap`, `fe07b2cf`/`4f254ef4 fix(robot): recalibrate encoder for new drive motor,
add PID-step debug log`, `bbd6803f feat(hardware): raise the speed ladder for the REV HD Hex
motor`. Ver también `encoder_counts_per_rev_is_60_not_86_2026_08_29` y
`motor_servo_bench_session_2026_08_28`.

---

### [2026-08-27→28] El puente H se recableó y el firmware de calibración de servo tenía un fallo en los nombres de carpeta

**Categorías:** `puente-h` `eléctrico` `servo` `mecánica`

**Contexto/restricción:** junto con el cambio de motor, el puente H (BTS7960) se recableó
físicamente, lo que invirtió el sentido eléctrico esperado de la señal `drive.reversed`
(commits `8e83945c`/`8fccb633 fix(robot): flip drive.reversed for the BTS7960 rewire`) - un
recordatorio de que un cambio de cableado físico también es una entrada que debe
propagarse al software, no solo un detalle de electrónica.

**Qué hicimos (fallo del servo, hallado por separado):** se descubrió que la capa de
configuración para el servo de dirección (`range_deg=270`, para el servo Hiwonder de 35 kg
realmente instalado) nunca se había aplicado en hardware. La función que carga las capas por
nombre de perfil (`_profile_overlay_paths()`) construye la ruta a partir del nombre de
`VTITAN_HARDWARE_PROFILE` y **si la carpeta no existe, la omite en silencio, sin error ni
señal**. La carpeta estaba nombrada `servo270`, que nunca coincidió con el nombre real del
perfil activo (`270deg-hiwonder-35kg`) - así que cada comando de servo estuvo usando
matemática de ancho de pulso para un servo de **180°**, en un servo físico de **270°**, desde
que se instaló.

**Por qué importa:** este es un cambio de comportamiento real una vez desplegado, no solo una
corrección cosmética - el mismo ángulo comandado ahora mapea a un swing de ancho de pulso
distinto (ej. 67.5° pasa de 2250 µs a 2000 µs), así que la dirección se siente **menos
agresiva por grado** en ángulos intermedios que antes. Se documentó explícitamente como algo
que requiere reverificación en hardware, no solo confiar en la corrección de código.

**Resultado medido:** corrección de nombre de carpeta aplicada; además se corrigieron
referencias obsoletas a "servo270" en docs, Taskfile y texto de ayuda del generador Go, y un
error en `docs/servo-comparison-180-vs-270.md` que indicaba reiniciar el servicio equivocado
(`vtitan-pi5.service` en vez de que `ackermann_motor_node` corre en el Pi Zero).

**Referencia:** commit `3a7d7cbe fix(robot): rename servo270 profile folder to match active
profile name`.

### Lo que falta de mecánica

Nos falta material gráfico. Hace falta un diagrama dimensionado del chasis (30 × 19.4 cm,
1.3 kg) y de la disposición de las ruedas (7 cm de diámetro), tomando `robot.toml` como fuente
de verdad para las cotas. Hacen falta también fotos o el CAD de la dirección Ackermann que
fabricamos, y conviene decir de forma explícita que **no** es el chasis LEGO Bugatti Bolide,
porque a simple vista se parecen y la diferencia es justo lo que fabricamos nosotros.

Queda pendiente además escribir la sesión de banco de motor y servo del 28 de agosto como una
iteración con datos de antes y después de la retonificación del PID. Esa entrada debe incluir
la reverificación en vivo del reescalado de ganancias, que sigue sin hacerse.

---

## 2. Power and Sensor Architecture

### [2026-08-21] Los perfiles de hardware son por componente, no globales

**Categorías:** `arquitectura` `software`

**Contexto/restricción:** el sistema soporta simulación y hardware real, y cada
componente (LIDAR, cámara, motores) necesita saber si está hablando con hardware real o con
un simulador.

**Qué hicimos:** implementamos perfiles de hardware **por componente** en vez de un único
indicador global, y documentamos que un perfil sin activar no tiene efecto aunque el archivo esté
editado.

**Por qué:** un indicador global obliga a que todo el sistema esté en modo simulación o todo en modo
hardware; en la práctica necesitamos combinaciones (ej. LIDAR real + resto simulado) durante
la puesta a punto.

**Resultado medido:** N/A (decisión de arquitectura); efecto colateral documentado: si el
perfil no está seteado, el import falla en vez de fallar en silencio con comportamiento
incorrecto.

**Referencia:** `hardware_profiles_are_per_component_2026_08_21`,
`hardware_profile_not_activated_2026_08_20`.

---

### [2026-08-22] Recalibración de la distancia de giro por el desplazamiento físico del LIDAR

**Categorías:** `sensores` `lidar` `calibración`

**Contexto/restricción:** el LIDAR no está montado en el centro geométrico del chasis, así
que las distancias de holgura para las maniobras de giro medidas "desde el LIDAR" no
coincidían con el espacio real disponible para el chasis.

**Qué hicimos:** recalibramos las distancias de holgura de giro teniendo en cuenta el desplazamiento
físico del sensor respecto al centro del chasis.

**Por qué:** ignorar ese desplazamiento produce un sesgo sistemático - el robot "cree" tener más o
menos espacio del que realmente tiene, según el punto del giro.

**Resultado medido:** constante `TURN_CLEARANCE_M` anterior quedó invalidada por el cambio de
calibración.

**Referencia:** `lidar_offset_clearance_recalibration_2026_08_22`.

---

### [2026-08-31] El montaje invertido del LIDAR necesita un espejo, no una rotación de 180°

**Categorías:** `sensores` `lidar` `software`

**Contexto/restricción:** el LIDAR está montado invertido en el chasis. La corrección
"ingenua" para un montaje invertido es sumar 180° al ángulo reportado.

**Opciones consideradas:** corregir con `+180°` (rotación) vs. corregir invirtiendo el eje
angular (espejo).

**Qué hicimos:** identificamos que un montaje invertido requiere **espejar** el ángulo
decodificado, no rotarlo, y corregimos el controlador en la migración a Go
(`2ebe7d7d fix(lidar): mirror decoded angles for an inverted mount, not rotate`).

**Por qué:** rotar 180° preserva la orientación (quiralidad) del barrido, mientras que un
montaje invertido físicamente invierte esa quiralidad - son transformaciones distintas y una
sustituye mal a la otra. Usar la incorrecta produce lecturas de ángulo consistentemente mal
mapeadas, especialmente notorio en los sectores laterales/traseros.

**Resultado medido:** corregido en la implementación Go (`robot-go`); la implementación
Python (`LidarYawOffsetRad()` / `sector.go` / `_LIDAR_YAW_OFFSET_RAD`) quedó identificada como
pendiente de corregir en conjunto para no divergir entre ambas.

**Referencia:** `lidar_inverted_mount_needs_mirror_not_rotation_2026_08_31`.

---

### [2026-08-22] Un indicador de localización por LIDAR estaba invertido en su semántica

**Categorías:** `sensores` `lidar` `software`

**Contexto/restricción:** el indicador `use_lidar_localization` se interpretaba de forma
contraintuitiva: `True` hacía el problema de localización **más difícil**, no más fácil, al
contrario de lo que su nombre sugiere.

**Qué hicimos:** documentamos explícitamente el comportamiento real del indicador para evitar que
futuras pruebas lo usaran con la semántica intuitiva incorrecta.

**Por qué:** un indicador con semántica invertida y sin documentar es una fuente silenciosa de
errores de experimento - cualquier A/B hecho asumiendo la semántica "obvia" mide lo contrario
de lo que cree medir.

**Referencia:** `use_lidar_localization_reads_backwards_2026_08_22`.

---

### [2026-08] El puente H (BTS7960) mantuvo el motor girando a máxima velocidad en reversa al arrancar - historia de un fallo de seguridad en tres capas

**Categorías:** `puente-h` `eléctrico` `seguridad`

**Contexto/restricción:** el controlador de motor emplea un puente H BTS7960 controlado por GPIO
(habilitación `R_EN`/`L_EN`) y PWM (`RPWM`/`LPWM`). Se descubrió en hardware que, en ciertas
condiciones, el motor arrancaba girando a máxima velocidad en reversa sin que el software de
control hubiera comandado eso - un fallo de seguridad grave, no cosmético.

**Capa 1 - secuenciación de habilitación (`f0fc617b`/`d8791b89`):** se identificó que
`R_EN`/`L_EN` podían quedar en HIGH (habilitados) antes de que los canales PWM estuvieran
confirmados en 0% duty. Se corrigió para que ambos canales PWM se confirmen en 0 antes de
habilitar el puente H - invariante que después se preservó explícitamente al portar el controlador
a Go (`511d0a00`/`01e7cb78`), con pruebas dedicadas
(`TestController_Connect_NeverEnablesBeforeZeroingEitherChannel`,
`TestController_SetSpeed_NeverBothChannelsNonzero`) para que nunca se reintroduzca en
silencio.

**Capa 2 - flotación de GPIO al arrancar (`bd60aa82`/`f5797c6a`):** con la capa 1 corregida,
seguía pasando que el motor giraba a máxima reversa **antes** de que el nodo de control
siquiera arrancara. Se midió en hardware que un pull-down *pasivo* de GPIO
(`gpio=...=pd`) no cierra la ventana de arranque: el propio nivel-shifter del BTS7960 tiene
un pull-up interno de ~10 kΩ por canal, que le gana al pull-down interno del SoC (mucho más
débil, ~50 kΩ). Ese hueco dejaba que el motor de tracción girara a máxima velocidad en
reversa antes de que `connect()` del nodo del motor llegara a ejecutarse. La solución que sí
funcionó, verificada en hardware con el servicio systemd deshabilitado: manejar esos 3 pines
como salida activa forzada a bajo (`gpio=...=op,dl`) desde firmware, confirmando en un
arranque limpio que los pines se mantienen bajos desde el arranque mismo, y que `gpiozero`
los puede seguir reclamando después sin conflicto cuando el servicio arranca.

**Capa 3 - flotación de GPIO al detener el servicio (`a55612b4`/`96020000`):** un
`systemctl stop` normal, o cualquier caída del proceso, libera los descriptores de archivo
GPIO que `gpiozero` retiene para `LPWM`/`R_EN`/`L_EN`. En el momento en que se liberan, el
pull-up del nivel-shifter los vuelve a arrastrar a HIGH. Lo reprodujimos en vivo: motor a
máxima reversa en un `stop` rutinario, no solo en arranque en frío. La corrección de
`config.txt` (`op,dl`) de la capa 2 solo cubre la ventana de arranque, porque es una
instrucción de firmware de una sola vez, no un valor por defecto que se reaplique al liberar
el pin. Usamos
`ExecStopPost` de systemd, que se ejecuta después de que el proceso principal termina por
cualquier razón que systemd conozca, para volver a forzar esos pines a bajo. Eso cierra la
mayor parte del hueco sin tocar el ciclo de vida ni el apagado propios del nodo.

**Por qué importa:** esta cadena de tres capas **no cubre todos los casos**, y lo dejamos
dicho aquí en lugar de darla por cerrada. Una pérdida de energía cruda seguiría dejando los
pines flotando, y la mitigación completa, una resistencia pull-down física en `LPWM`,
**todavía no está instalada**. Es un modo de falla identificado con mitigación parcial y un
riesgo residual que sigue vivo; queda repetido en la sección 4 para que no se pierda.

**Referencia:** `gpio_boot_float_full_speed_motor_2026_08_27`,
`gpio_float_reverse_on_script_to_service_handoff_2026_08_28`,
`bts7960_connect_ordering_bug_2026_08_28`. Commits: `f0fc617b`, `d8791b89`, `bd60aa82`,
`f5797c6a`, `a55612b4`, `96020000`, `9748b30d fix(robot): template the BTS7960 GPIO pins into
the systemd stop-hook`, `873a1232 fix(robot): re-drive BTS7960 GPIO pins low on driver
disconnect`.

---

### [fecha no registrada] El diseño de cableado del puente H cambió de PWM compartido a RPWM/LPWM independientes

**Categorías:** `puente-h` `eléctrico`

**Contexto/restricción:** el diseño original de `driver.py`/`config.py` alimentaba el puente
H con un PWM compartido hacia un demultiplexor externo, en vez de usar las dos señales
`RPWM`/`LPWM` del BTS7960 de forma verdaderamente independiente.

**Qué hicimos:** se migró a señales `RPWM`/`LPWM` independientes (commit `6aee1ac2`), y
posteriormente se detectó que la documentación (`.env.example`, comentarios de
`bts7960.toml`, el docstring de `ackermann_motor_node`, y los tests) seguía describiendo el
diseño viejo de demux compartido y los pines `R_EN`/`L_EN` intercambiados.

**Por qué:** documentación desincronizada del cableado real es peligrosa específicamente en
un componente de seguridad (control de motor) - alguien depurando con la documentación vieja
llegaría a conclusiones incorrectas sobre qué pin hace qué.

**Resultado medido:** confirmado en vivo en hardware (registros del Pi Zero): `forward=13`,
`reverse=26`, `r_en=6`, `l_en=5`, conecta y activa limpiamente con el diseño independiente.

**Referencia:** commit `dcec0b93 docs(robot): catch up BTS7960 env/toml/test docs to
independent RPWM/LPWM`.

---

### [fecha no registrada] La cámara estaba montada invertida y el indicador de software nunca se activó

**Categorías:** `sensores` `cámara` `software`

**Contexto/restricción:** la cámara está físicamente montada boca abajo en el chasis. La
lógica de rotación y volteo para compensar un montaje invertido ya existía en el controlador, pero el
indicador `camera_inverted` estaba en `false` por defecto en ambos TOML de configuración del
controlador.

**Qué hicimos:** activamos `camera_inverted` por defecto.

**Por qué:** este no era solo un problema estético de imagen volteada - el frame sin rotar
estaba **espejando silenciosamente izquierda/derecha**, lo cual afectaba directamente la
detección del lado de paso de señales (pass-side), uno de los fallos más caros del desafío
(ver Criterio 3 y 4). Es un buen ejemplo de cómo un defecto de montaje mecánico/óptico se
manifiesta como un fallo de "lógica" aguas abajo si no se corrige en la fuente.

**Resultado medido:** corrección directa del defecto de imagen espejada; efecto colateral
positivo documentado explícitamente en la detección de pass-side.

**Referencia:** commit `78c1692e fix(robot): enable camera_inverted for upside-down camera
mount`.

### Arquitectura de sensores

- **Cómputo:** NPU Hailo-8 para aceleración de inferencia.
- **Cámara:** Raspberry Pi Camera Module 3 Wide, 102° de campo de visión horizontal.
- **LIDAR:** Slamtec C1 (modo *dense*; se identificó y corrigió un mismatch de modo de
  escaneo que producía lecturas de rango erróneas - `lidar_c1_dense_mode_scan_mismatch`).
- **IMU:** BNO085.
- **Chasis:** Ackermann personalizado, no un kit LEGO.

### Lo que falta de potencia y sensores

El hueco más grande de este criterio es el presupuesto de potencia: hoy no lo tenemos
calculado formalmente, solo conocemos el tope de velocidad del tren motriz. Hay que medir el
consumo en pico y en reposo, y desglosarlo por rama sobre un diagrama de cableado real que vaya
de la batería a los reguladores y de ahí a motores y electrónica.

El método de calibración de la cámara y de la IMU sí existe, pero vive disperso en notas de
sesión. Falta consolidarlo en un procedimiento paso a paso que otro equipo pueda seguir.

---

## 3. Software Architecture and Obstacle Strategy

> **⚠️ Salvedad de medición (agregado 2026-09-05):** el commit `ecc3cdef fix(sim): only score a
> sign pass the scorer actually watched happen` corrigió el sistema de puntaje de pass-side -
> antes, ser *colocado* más allá del radio de una señal dentro de 1.20 m contaba como paso por
> el lado incorrecto, aunque el robot nunca hubiera hecho esa aproximación. **Todas las cifras
> de Obstacles citadas en esta sección (y en la sección 4) fueron medidas antes de esa
> corrección y no son directamente comparables con mediciones posteriores.** El efecto conocido
> es que corridas que antes terminaban temprano ahora sobreviven hasta chocar contra algo real:
> las colisiones de control suben de 5 a 14. Antes de citar cualquiera de estos números como
> estado actual, volver a medir con el evaluador corregido.

### [2026-09-02] Dos maniobras de salida de bahía, decididas por el modelo de contacto físico

**Categorías:** `software-navegación` `obstáculos` `parking` `decisión-sistema`

**Contexto/restricción:** existían dos implementaciones candidatas para la maniobra de salida
de la bahía de estacionamiento (el "bay exit"), cada una con éxito casi perfecto (254/256)
bajo *distintos* modelos de contacto de simulación - la que ganaba dependía enteramente de
si el modelo de contacto permite "deslizar" contra la pared o la hace "trincar" (ratchet).

**Opciones consideradas:** (a) `0f277aa1` - salida que fija ("latches") el lado abierto y
mantiene el steering, compatible con un modelo de contacto que trinca; (b) `ae15ee3e` -
salida cíclica de 26°, con steering fijado antes de avanzar, compatible con un modelo de
contacto que desliza.

**Qué hicimos:** enviamos `ae15ee3e` (modelo *slide*) como comportamiento por defecto.

**Por qué:** dos hallazgos independientes se juntaron aquí. Por un lado determinamos que el
simulador **nunca desliza** contra una pared, una limitación de fidelidad conocida: a 20° de
incidencia el progreso es 56 veces menor que con deslizamiento real. Por otro, el reglamento
WRO 2026 establece que **tocar los límites del cajón de estacionamiento anula todos los puntos
de parking**.

Juntos implican que cualquier maniobra que necesite contacto sostenido con la pared para
"funcionar" en simulación está modelando una infracción, no una estrategia. Por eso
descartamos el modelo `--solid-walls`, que premia el contacto: haría que el simulador puntuara
como éxito algo que en la pista real es una descalificación.

**Resultado medido:** ambas maniobras llegan a 254/256 en simulación bajo su modelo
respectivo; la decisión de cuál enviar no se tomó por la métrica de simulación (empatada)
sino por cuál corresponde a comportamiento legal según el reglamento.

**Referencia:** `bay_exit_solved_by_hold_steer_2026_09_02`,
`wro_2026_scoring_parking_and_bay_start_2026_09_03`. Commits:
`0f277aa1`, `544958be`, `ae15ee3e feat(nav): ship the cycle bay exit`.

Esta entrada pertenece también al **criterio 4**: la decisión no se tomó por el resultado en
simulación, sino por una restricción externa, el reglamento, que la simulación por sí sola no
podía revelar.

---

### [2026-08-28] La maniobra de escape no debe avanzar hacia una pared que el robot no puede ver

**Categorías:** `software-navegación` `obstáculos` `sensores`

**Contexto/restricción:** la maniobra reactiva de "escape" (usada al detectar contacto o
proximidad de obstáculo) podía comandar avance hacia adelante incluso cuando el cono frontal
del LIDAR no tenía lecturas válidas (retorno nulo), lo cual el software interpretaba
erróneamente como "espacio libre" en lugar de "sensor degradado".

**Qué hicimos:** distinguimos explícitamente "cono sin retorno de LIDAR" (sensor degradado)
de "cono con retorno indicando espacio libre", y bloqueamos el escape hacia adelante en el
primer caso.

**Por qué:** tratar la ausencia de datos como "vía libre" es la peor interpretación posible
del silencio de un sensor - es exactamente la condición donde más probable es que haya un
obstáculo demasiado cerca o en un ángulo ciego.

**Resultado medido:** la corrección llevó la maniobra de 0 a 2 vueltas completadas en la
prueba de referencia usada en ese momento.

**Referencia:** `obstacles_escape_maneuver_forward_into_wall_2026_08_28`,
`obstacles_lidar_no_return_reads_as_clear_2026_08_28`. Commits:
`bda6b10c fix(nav): don't escape FORWARD into a wall the robot cannot see`,
`d638800b fix(nav): an unreadable forward cone is a degraded sensor, not open road`.

---

### [2026-09-01] El error de "pass-side" (lado de paso de señal) es de seguimiento, no de ruteo

**Categorías:** `software-navegación` `obstáculos`

**Contexto/restricción:** el robot ocasionalmente pasaba una señal (poste/obstáculo) por el
lado incorrecto, lo cual en el reglamento WRO no solo vale 0 puntos sino que **termina la
ronda** (regla 9.24.5) - el fallo más caro posible en este desafío.

**Opciones consideradas:** la hipótesis inicial era que el planificador de ruta (el "enrutador")
elegía el lado incorrecto (fallo de decisión o de enrutado). La hipótesis alternativa era que el
enrutador decidía bien pero el controlador de seguimiento de trayectoria no ejecutaba esa
decisión con suficiente margen.

**Qué hicimos:** medimos: el plan de ruta acertaba el lado correcto en 642 de 642 casos, con
un margen de diseño de 5.6 cm - es decir, el enrutador **no** era el problema.

**Por qué:** esto redirigió todo el esfuerzo de esta rama de trabajo desde "corregir el
enrutador" (que ya estaba bien) hacia "reducir el error de seguimiento" que consumía el
margen de 5.6 cm en la ejecución real.

**Resultado medido:** confirmó y superó una hipótesis anterior ("fallo de enrutado") y otra más
antigua ("puntuado sobre creencia, no verdad de terreno") que ya habían sido corregidas por
separado. Trabajo posterior (`sign_pass_error_is_outward_bias`) encontró que el error
residual es un **sesgo sistemático hacia afuera** (84% de los casos, +7.53 cm vs. 5.6 cm de
margen), no dispersión aleatoria - lo cual implica que es corregible ajustando la puntería
del controlador, no agregando más margen de seguridad.

**Referencia:** `obstacles_pass_side_is_tracking_not_routing_2026_09_01`,
`sign_pass_error_is_outward_bias_not_scatter_2026_09_03`,
`pass_side_is_a_round_ender_and_convention_may_be_wrong_2026_09_03`.

---

### [2026-08-31] `OBSTACLES_CONTACT_DIST` a 0.05: mejora medible, con un costo aceptado

**Categorías:** `software-navegación` `obstáculos` `decisión-sistema`

**Contexto/restricción:** el umbral de distancia de contacto que dispara la maniobra de
escape reactivo (`OBSTACLES_CONTACT_DIST`) estaba en un valor que dejaba muchos casos sin
activar el escape a tiempo.

**Qué hicimos:** movimos el umbral a 0.05 m y medimos el efecto en una corrida de referencia
de 256 casos: vueltas completadas subieron de 68 a 434 (agregado), vueltas-por-run ≥3 subieron
de 11 a 82, y los timeouts bajaron de 126 a 48.

**Por qué:** un umbral más sensible detecta contacto inminente antes, dando más tiempo a la
maniobra de escape para ejecutarse con margen.

**Resultado medido:** mejora neta clara en finalización de vueltas y reducción de timeouts,
**pero** con una regresión aceptada conscientemente: los casos de "pass-side" (el fallo más
caro, ver entrada anterior) empeoraron de 82 a 122. Se documentó explícitamente como
trade-off pendiente de resolver por la vía del seguimiento, no revirtiendo este cambio.

**Referencia:** `obstacles_contact_dist_is_shippable_and_pass_side_is_next_2026_08_31`.
Commit: `1de8094d feat(nav): ship the Obstacles contact zone at 0.05`.

---

### [2026-09-02] El límite del corredor de escape lateral no puede excluir ningún rumbo a distancia de contacto

**Categorías:** `software-navegación` `obstáculos`

**Contexto/restricción:** se investigó si el corredor de escape lateral (la zona angular que
la maniobra de escape considera "segura" para desviarse) podía restringirse geométricamente
para evitar que el escape empujara al robot hacia el lado incorrecto de una señal.

**Qué hicimos:** medimos que, a la distancia de contacto real, el corredor de escape se
degenera - no existe ningún rumbo que el corredor pueda excluir sin también excluir rumbos
necesarios para escapar del obstáculo inmediato. El 82% de los escapes están impulsados por
esta "puerta" geométrica, y el 92% son de tipo lateral.

**Por qué:** esto **refutó** una hipótesis previa de que la capa reactiva de escape podía
usarse para reducir directamente los casos de "pass-side" - la geometría a esa distancia no
lo permite. Se documentó explícitamente como descripción, no como prescripción: la solución
tiene que venir de la capa de seguimiento (ver la entrada anterior), no de la capa reactiva.

**Referencia:** `escape_gate_corridor_degenerates_at_contact_range_2026_09_02`,
`lateral_escape_is_load_bearing_2026_09_02` (que además refutó la opción de simplemente
suprimir el escape lateral: hacerlo reduce pass-side de 122 a 80 pero dispara las colisiones
con señales de 4 a 97 - un trade-off mucho peor).

---

### [2026-09-02] Escalera de velocidad de Open elevada a 0.26/0.38/0.50 m/s

**Categorías:** `software-navegación`

**Contexto/restricción:** la escalera de velocidad del desafío Open (velocidades objetivo en
tramos sucesivos) estaba en valores conservadores; había margen de tiempo sin usar si se
pudiera subir sin introducir colisiones.

**Qué hicimos:** elevamos la escalera a 0.26/0.38/0.50 m/s y verificamos 639/640 corridas sin
colisión en el corpus de referencia. Se probó también 0.60 m/s como siguiente escalón.

**Por qué:** 0.60 m/s resultó ser un **acantilado de colisión** (salto brusco en tasa de
fallos, no degradación gradual) - se documentó explícitamente para que nadie vuelva a subir
la escalera a ese valor asumiendo que la mejora escala linealmente con velocidad.

**Resultado medido:** 639/640 sin colisión con la escalera actual; 0.60 m/s descartado por el
comportamiento de acantilado.

**Referencia:** `open_speed_ladder_raised_to_050_2026_09_02`. Commit:
`a98bcbc4 feat(nav): raise the Open speed ladder, and stop justifying it with a stale lap time`.

---

### Arquitectura del software

- Control de trayectoria por **pure pursuit** (`waypoint_controller`), con un
  navegador central (`core_navigator`) que separa planificación de ruta, seguimiento de
  trayectoria y una capa reactiva de escape ante contacto/proximidad.
- La estrategia de obstáculos emplea un enrutador de "lado de paso" (pass-side) separado del
  controlador de seguimiento - la investigación de este año confirmó que el enrutador es correcto
  y que el error reside en el seguimiento, lo cual cambió el foco del trabajo (ver arriba).
- Migración en curso de partes del software de Python (ROS2/rclpy) a Go (`robot-go`) sobre
  transporte NATS, en fases documentadas.

### Lo que falta de software

La máquina de estados completa, desde el arranque en la bahía hasta el estacionamiento pasando
por Open y Obstacles, solo existe hoy como código y notas dispersas. Falta dibujarla como
diagrama de flujo.

Falta también reunir en un solo lugar las métricas con las que ajustamos: tasa de colisión,
vueltas completadas, error de trayectoria y tasa de paso por el lado correcto. Ahora mismo cada
una se explica dentro de la entrada donde apareció, y no hay un solo sitio donde
consultarlas juntas.

---

## 4. Systems Thinking and Engineering Decisions

### [2026-09-03] El modelo de contacto por defecto se elige por reglamento, no por score de simulación

**Categorías:** `decisión-sistema` `parking` `reglamento`

**Contexto/restricción:** el reglamento oficial WRO 2026 establece que tocar los límites del
cajón de estacionamiento durante el parking **anula todos los puntos de parking**, no solo
resta puntos parciales.

**Qué hicimos:** revisamos todas las estrategias de bay-exit/parking que dependían de
contacto sostenido con la pared para funcionar en simulación (incluyendo una que lograba
254/256 usando `--solid-walls`) y las descalificamos como estrategia válida, aunque su
métrica de simulación fuera excelente. Se fijó el modelo de contacto **por defecto** (no el
de paredes sólidas) como el que se debe usar para cualquier evaluación futura.

**Por qué:** optimizar contra una métrica de simulación que no captura una regla de
descalificación del reglamento real produce un robot que "gana" en simulación y pierde todos
los puntos de parking en la pista real. Es el ejemplo más claro del proyecto de por qué la
simulación **no sustituye** la lectura del reglamento.

**Resultado medido:** N/A (es una decisión de política de ingeniería, no un experimento) -
pero desbloqueó la decisión correcta entre las dos maniobras de bay-exit empatadas en score
(ver Criterio 3, `ae15ee3e` vs. `0f277aa1`).

**Referencia:** `wro_2026_scoring_parking_and_bay_start_2026_09_03`.

---

### [2026-09-03] El "pass-side" es la falla más cara del desafío, y su convención de medición está bajo sospecha

**Categorías:** `decisión-sistema` `riesgo-abierto` `reglamento`

**Contexto/restricción:** el reglamento define el lado de paso correcto **relativo al sentido
de viaje** del robot (rojo a la derecha del sentido de marcha), pero el enrutador y el sistema
de puntaje interno del proyecto lo definen en términos **absolutos**. Ambas convenciones
coinciden en sentido antihorario, pero **difieren en sentido horario** - y la simulación
actual no puede exponer esta diferencia porque no varía el sentido de la pista de forma que
la distinga.

**Qué hicimos:** documentamos el riesgo explícitamente como **no resuelto** y decidimos
**no cambiar la convención unilateralmente** - se marcó como pendiente de confirmar con
criterio humano antes de modificar el enrutador o el evaluador de puntaje, precisamente porque un cambio
incorrecto aquí podría "arreglar" una convención que en realidad estaba bien, y esconder el
problema real.

**Por qué:** dado que un fallo de pass-side termina la ronda completa, el costo de cambiar la
convención incorrectamente es mucho mayor que el costo de dejarlo documentado y pendiente.
Es una decisión consciente de **no actuar todavía** ante incertidumbre de alto impacto, en
vez de "arreglar" algo sin estar seguros de qué lado del problema se está viendo.

**Resultado medido:** riesgo identificado, con nota explícita de "preguntar antes de
cambiar" - ejemplo directo de identificación de riesgo + mitigación por precaución, en vez
de por corrección de código.

**Referencia:** `pass_side_is_a_round_ender_and_convention_may_be_wrong_2026_09_03`.

---

### [2026-09-03] Los resultados de los barridos no son comparables entre sí si hay ediciones concurrentes

**Categorías:** `metodología` `pruebas`

**Contexto/restricción:** el mismo conjunto de pruebas ("arm") dio 21/256 fallos en una
corrida y 5/256 en otra corrida posterior, sin cambios de código propios que lo explicaran.

**Qué hicimos:** investigamos y encontramos que una sesión de desarrollo **concurrente**
estaba editando código de parking/simulación mientras la corrida de referencia se ejecutaba,
contaminando la comparación. Se estableció como regla de proceso: los resultados de un barrido
sólo son comparables **dentro de una misma invocación**, nunca entre corridas separadas en el
tiempo si hubo cambios concurrentes en el repositorio.

**Por qué:** sin esta regla, cualquier mejora o regresión aparente podría ser ruido de
concurrencia, no una señal real del cambio bajo prueba - un riesgo serio para la validez de
todas las conclusiones de ajuste del proyecto.

**Resultado medido:** se adoptó `--strip-parking` como forma de aislar resultados de
obstáculos del ruido introducido por trabajo paralelo en parking.

**Referencia:** `sweep_results_not_comparable_across_time_2026_09_03`.

---

### [en curso, desde ~2026-08] Migrar el software del robot de Python/ROS2 a Go/NATS: una decisión de arquitectura, no una reescritura por gusto

**Categorías:** `arquitectura` `decisión-sistema` `software`

**Contexto/restricción:** el software original se ejecuta sobre Python con ROS2 (rclpy) como
framework de nodos/transporte. El primer commit de esta migración lo describe explícitamente
como el **"reemplazo a largo plazo de ROS2"** (`258f1f9e feat(robot-go): scaffold Go/NATS
workspace for the long-term ROS2 replacement`), no como un experimento paralelo.

**Opciones consideradas:** quedarse en Python/ROS2 e invertir el esfuerzo de mejora en ese
sistema, frente a migrar de forma incremental a Go sobre transporte NATS, nodo por nodo (controladores de
hardware primero: BTS7960, LIDAR, IMU, botón, OLED; luego telemetría y máquina de estados
central), preservando invariantes de seguridad ya verificadas en la implementación Python
(ej. la secuenciación de habilitación del puente H, ver arriba, portada explícitamente con
pruebas dedicadas).

**Qué hicimos:** se ejecutó como migración **por fases**, documentada aparte
(`go_nats_migration_plan`), con cada controlador de hardware portado y re-verificado
individualmente contra el hardware real antes de avanzar (ej. el controlador de LIDAR en modo classic
primero, luego un controlador aparte para el modo Dense cuando se detectó que el modo de escaneo
importaba - ver `lidar_c1_dense_mode_scan_mismatch`). A la fecha de esta entrada, ~99
commits tocan el árbol `robot-go`, cubriendo transporte, controladores de todos los sensores y
actuadores, un supervisor de reinicio con notificación a systemd, y agregación de
telemetría.

**Por qué:** las razones completas para elegir Go en lugar de seguir invirtiendo en
Python/ROS2 no están consolidadas en un solo documento, y eso sigue pendiente (ver el cierre
de esta entrada). Pero la ejecución en sí ya contiene dos decisiones de sistema explícitas.

La primera es migrar **incrementalmente por componente**, no todo de una vez, para poder
validar cada pieza contra hardware real de forma aislada.

La segunda es **no perder por el camino las invariantes de seguridad ya ganadas**. El ejemplo
más claro es la corrección de secuenciación de habilitación del puente H: se halló y se
corrigió en Python, y al portarla a Go la acompañamos de pruebas explícitas que codifican esa
invariante, en vez de confiar en que el código nuevo no repetiría el fallo.

**Resultado medido:** migración en curso, no completa (fases documentadas por separado,
casillas de progreso ya desactualizadas respecto al código real - hay que verificar contra
el árbol antes de citar como terminado cualquier fase específica).

**Referencia:** `go_nats_migration_plan`, `go_migration_progress` (a través de Fase 5),
`bts7960_connect_ordering_bug_2026_08_28`. Commit inicial: `258f1f9e`/`43662ee0`.

Falta escribir el razonamiento de **por qué Go y no seguir en Python/ROS2** (rendimiento,
tipado, consumo de recursos en la Pi Zero, concurrencia) como una entrada propia. Hoy vive
implícito en las decisiones de código, y no como la comparación explícita de trade-offs que un
hace falta para juzgar la decisión desde fuera.

---

### [riesgo abierto] El pull-down físico de `LPWM` sigue sin instalarse

**Categorías:** `puente-h` `eléctrico` `riesgo-abierto`

**Contexto/restricción:** la cadena de tres capas de mitigación del fallo de GPIO flotante del
puente H (ver Criterio 2) cierra la ventana de arranque en frío y la ventana de detención de
servicio, pero **no cubre una pérdida de energía cruda** (corte de batería, desconexión
abrupta) - en ese caso los pines vuelven a flotar y el pull-up interno del nivel-shifter
puede volver a llevar el motor a máxima reversa.

**Qué hicimos:** documentamos explícitamente que la mitigación completa (una resistencia
pull-down física soldada en `LPWM`) es conocida, está identificada como la solución que sí
cubre el caso restante, y **todavía no está instalada** físicamente en el robot.

**Por qué se documenta como riesgo y no se cierra en falso:** una mitigación de software de
tres capas se siente "casi completa", y es tentador reportarla como resuelta. Documentar
explícitamente el caso que **no** cubre evita asumir una seguridad
que no existe todavía - especialmente relevante para un componente que puede mover el chasis
a máxima velocidad sin comando del software.

**Referencia:** `gpio_boot_float_full_speed_motor_2026_08_27` (nota: título dice "NOT FULLY
FIXED").

---

### Restricciones del sistema identificadas explícitamente

- **Físicas:** techo de velocidad real 0.58 m/s, radio de giro mínimo real medido en banco,
  chasis 1.3 kg / 30×19.4 cm - todos usados como límites duros del controlador, no solo como
  datos de referencia.
- **De cómputo:** NPU Hailo-8 como aceleración obligatoria para mantener el pipeline de
  visión dentro de presupuesto de tiempo real.
- **De reglamento:** contacto con límites de parking anula puntaje completo (no parcial);
  pass-side termina la ronda - ambas restricciones, no técnicas sino normativas, condicionan
  directamente qué soluciones técnicas son aceptables aunque simulen bien.
- **De fidelidad de simulación:** el modelo de contacto no desliza contra paredes (ver
  Criterio 3) - cualquier ajuste que dependa de ese comportamiento está sobreajustado al
  simulador, no al robot real. Esta es una restricción epistemológica, no física: limita qué
  conclusiones de simulación se pueden confiar sin validación en hardware.
- **De seguridad eléctrica no cerrada del todo:** el fallo de GPIO flotante del puente H (ver
  Criterio 2) está mitigado en software en tres capas, pero el caso de pérdida de energía
  cruda sigue dependiendo de una resistencia física aún no instalada - restricción de
  hardware pendiente, no de software.

---

## 5. Reproducibility and GitHub Quality

El repositorio acumula 1365 commits (medido el 2026-09-09), todos con la convención
`tipo(alcance): mensaje` (`feat(nav):`, `fix(sim):`, `docs(readme):`, `perf(nav):`). El
`README.md` ronda los 110.000 caracteres. Ambas cifras superan con holgura los mínimos
cuantitativos del Apéndice C, aunque
ese no era el objetivo: la convención de commits se adoptó porque el historial es nuestra
primera fuente para reconstruir cuándo y por qué cambió algo, y varias entradas de esta
bitácora se escribieron leyendo `git log`.

La estructura separa `src/python` (el sistema de navegación en Python/ROS2), `src/go`
(la migración en curso), `src/python/shared` (la configuración y el ajuste que ambos comparten) y
`docs/`, con sus subcarpetas `internal`, `development`, `proposals`, `reference` y `schemes`.
Las dependencias se gestionan con `uv` en Python y con Pixi/RoboStack para ROS2, y las
operaciones habituales están encapsuladas en el `Taskfile` (`task sim:navigate...`,
`task rpi:stack`) para que nadie tenga que reconstruir de memoria un comando largo.

### Lo que falta de reproducibilidad

El historial es continuo pero no está etiquetado: hay que marcar con tags los hitos de
competencia (`v1.0` para el regional, `v2.0` para el final internacional) y acompañarlos de
notas de versión. Falta también un `tests.md` que explique el flujo de pruebas de forma
centralizada, porque hoy está repartido entre notas de sesión.

El CAD y los diagramas de cableado que faltan en los criterios 1 y 2 tienen que acabar
**dentro** del repositorio, no solo referenciados desde él: una documentación que apunta a
archivos que no viaja con ella no es reproducible.

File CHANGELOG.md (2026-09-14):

# Historial de versiones de vTitan

Cada etiqueta marca un estado del robot que existió de verdad: o compitió, o se
desplegó en las placas y corrió rondas completas. Entre etiquetas el historial es
continuo, con mensajes de commit convencionales (`fix(nav):`, `feat(sim):`,
`perf(robot):`), así que cualquier cifra de esta documentación se puede rastrear
hasta el commit exacto que la produjo.

Las tres etiquetas `archive/*` no son versiones: son ramas de trabajo congeladas
para no perder su historia.

---

## v1.2 (13 de septiembre de 2026)

**216 commits desde v1.1.** La versión más grande de la temporada, y la que
cambió más el método, no solo el código.

**Enrutado por señales.** Se construyó el mapa de posiciones restringido por
reglas, primero apagado y después activado para su A/B de hardware. El
compromiso del enrutador con una señal ya no se suelta porque aparezca otro
pilar, y el planificador de carril de señales pasó a centrar el hueco cuando el
carril viene estrecho.

**Estacionamiento.** Pasó de ser código inalcanzable a ejecutable: el
aparcamiento se deriva ahora del arranque dentro de la bahía, que es lo que
permite que el controlador llegue siquiera a construirse.

**Mediciones que corrigieron supuestos.** El servomotor resultó ser **al menos el
doble de rápido de lo asumido, 2.4 rad/s medidos**, lo que resolvió la salida de
bahía. La cuota de detecciones verdes no se había desplomado: es una función del
**sentido de marcha**, y creerlo al revés había enviado a buscar un fallo que no
existía.

**Diagnósticos que recomendaron no construir.** Varios commits de esta versión
son análisis que terminaron en "no lo construyas": la maniobra de retroceso para
comprar pista se evaluó y se descartó con números. Un resultado negativo bien
medido ahorra más que uno positivo mal medido.

**45 refactorizaciones**, sobre todo consolidar constantes en una sola fuente y
migrar cargadores de configuración a estructuras generadas desde los esquemas.

## v1.1 (8 de septiembre de 2026)

**26 commits desde v1.0.** Versión estrecha y correctiva, posterior al evento
regional.

**Localización.** El robot ahora publica **si su estimación de posición explica
de verdad el barrido del LIDAR**, y tiene un camino de vuelta cuando deja de
explicarlo. Antes, una pose divergida era irrecuperable a mitad de ronda y
costaba la carrera entera.

**Geometría real del chasis.** Se le dio su radio de giro medido y un escape lo
bastante largo para poder usarlo. Hasta aquí el planificador pedía curvas que el
chasis no puede trazar.

**Fidelidad del simulador.** La cámara simulada pasó a quedarse ciega con la
distancia, como la real, y las cifras de calibración del modelo de alcance se
corrigieron midiéndolas en lazo cerrado.

**Fusión LIDAR y visión**, detrás de `SIGN_LIDAR_PROPOSE` y apagada por defecto:
el LIDAR propone **dónde** está una señal mientras la cámara sigue decidiendo
**qué** es.

## v1.0 (7 de septiembre de 2026)

**El estado con el que vTitan compitió en el evento regional de la WRO 2026.**
1311 commits desde el inicio del proyecto.

Contiene el robot completo tal y como se describe en el
[README](README.md): la pila ROS2 repartida entre Raspberry Pi 5 y Pi Zero 2 W,
el detector YOLO compilado para el AI HAT+, la navegación por pure pursuit con
control PI de velocidad, la máquina de estados de los dos desafíos, el
simulador con su corpus de escenarios de semilla fija, y el árbol de
configuración TOML que gobierna ambas implementaciones.

---

## Después de v1.2 (sin etiquetar)

70 commits. El trabajo en curso se ha concentrado en **cerrar la brecha entre el
simulador y el hardware**, porque varias conclusiones de temporada resultaron
ser artefactos del modelo y no del robot:

- El corpus ya no corre con **pose perfecta**: usa el presupuesto de error de
  sensor medido.
- La cámara emulada tiene la **tasa de detección y la latencia** del hardware.
- El chasis bloqueado **desliza a lo largo de la superficie** en vez de detenerse
  en seco, que era el mayor artefacto conocido del modelo de contacto.
- El servo simulado se mueve a la **velocidad del hardware**, no a la de la
  política de curva.
- Se modeló la **oclusión del propio chasis y la tasa real de pérdida** del
  LIDAR C1.

Estos cambios están marcados con `!` porque **invalidan comparaciones anteriores**:
un número medido antes de ellos no se resta con uno medido después.

---

## Convenciones

- **Etiquetas**: `vMAYOR.MENOR`, creadas cuando un estado se despliega y corre.
- **Mensajes de commit**: convencionales, en inglés. La documentación va en
  español.
- **`!` en el tipo** (`feat(sim)!:`) marca un cambio que rompe la comparabilidad
  de resultados anteriores, no solo la compatibilidad de una interfaz.
- **Firma**: los commits van firmados con GPG y aparecen como verificados.

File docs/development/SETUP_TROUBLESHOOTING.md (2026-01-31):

# Setup Script Troubleshooting Guide

## Common Errors and Fixes

### Error: `pip3: command not found`

**Problem:** The script tried to use pip3 before installing it.

**Fix:** The script has been updated to install `python3-pip` first.

**Manual fix if needed:**
```bash
# Install pip3
sudo apt install python3-pip python3-venv -y

# Then continue with Python packages
pip3 install --upgrade pip
pip3 install opencv-python opencv-contrib-python numpy scipy
pip3 install transforms3d
pip3 install --upgrade ultralytics
pip3 install onnxruntime
```

---

### Error: `E: Unable to locate package ros-kilted-gazebo-ros-pkgs`

**Problem:** Package name has changed in Kilted.

**Fix:** Use `ros-kilted-ros-gz` instead.

```bash
sudo apt install ros-kilted-ros-gz -y
```

See: `KILTED_PACKAGE_FIXES.md` for details.

---

### Error: `Release file for ... is not valid yet`

**Problem:** System clock might be wrong or repository metadata is from the future.

**Fix:**
```bash
# Check system time
date

# If wrong, sync time
sudo apt install ntpdate -y
sudo ntpdate time.nist.gov

# Update package lists
sudo apt update
```

---

### Error: `Ubuntu version is not 24.04`

**Problem:** Kilted requires Ubuntu 24.04 LTS (Noble Numbat).

**Fix:**
```bash
# Check Ubuntu version
lsb_release -a

# If not 24.04, you have two options:

# Option 1: Upgrade WSL to Ubuntu 24.04
wsl --install Ubuntu-24.04

# Option 2: Use ROS2 Humble on Ubuntu 22.04
# (See HUMBLE fallback guide)
```

---

### Error: `Could not get lock /var/lib/apt/lists/lock`

**Problem:** Another apt process is running.

**Fix:**
```bash
# Wait for other apt processes to finish, then:
sudo apt update

# If still locked after 5 minutes:
sudo rm /var/lib/apt/lists/lock
sudo rm /var/cache/apt/archives/lock
sudo rm /var/lib/dpkg/lock*
sudo dpkg --configure -a
sudo apt update
```

---

### Error: Python packages fail to install

**Problem:** Missing build dependencies.

**Fix:**
```bash
# Install build essentials
sudo apt install build-essential python3-dev -y

# Install pip dependencies
sudo apt install python3-pip python3-venv -y

# Retry pip installations
pip3 install --upgrade pip
pip3 install opencv-python opencv-contrib-python numpy scipy
```

---

### Error: `EXTERNALLY-MANAGED-ENVIRONMENT`

**Problem:** Ubuntu 24.04 uses externally managed Python environments.

**Fix (Option 1 - Recommended): Use virtual environment**
```bash
# Create virtual environment
python3 -m venv ~/teamsteelbot/klevor-v2/.venv

# Activate it
source ~/teamsteelbot/klevor-v2/.venv/bin/activate

# Install packages
pip3 install opencv-python opencv-contrib-python numpy scipy
pip3 install transforms3d ultralytics onnxruntime

# Add to ~/.bashrc for persistence
echo "source ~/teamsteelbot/klevor-v2/.venv/bin/activate" >> ~/.bashrc
```

**Fix (Option 2): Use system packages with --break-system-packages**
```bash
# Install with flag (not recommended, but works)
pip3 install --break-system-packages opencv-python
```

**Fix (Option 3): Use apt for system packages**
```bash
# Install what's available via apt
sudo apt install python3-opencv python3-numpy python3-scipy -y

# Only use pip for packages not in apt
pip3 install --user ultralytics onnxruntime transforms3d
```

---

### Error: Insufficient disk space

**Problem:** Not enough space for all packages.

**Fix:**
```bash
# Check available space
df -h

# Clean up if needed
sudo apt clean
sudo apt autoremove -y

# Increase WSL2 disk size (from Windows PowerShell):
# wsl --shutdown
# diskpart
# select vdisk file="C:\Users\YourUser\AppData\Local\Packages\...\ext4.vhdx"
# expand vdisk maximum=100000  # Size in MB
```

---

### Error: Network/download issues

**Problem:** Slow or failing downloads.

**Fix:**
```bash
# Try different Ubuntu mirror
sudo sed -i 's|http://archive.ubuntu.com|http://mirror.us.leaseweb.net|g' /etc/apt/sources.list
sudo apt update

# Or use main server
sudo sed -i 's|http://mirror.us.leaseweb.net|http://archive.ubuntu.com|g' /etc/apt/sources.list
sudo apt update
```

---

## Step-by-Step Manual Installation

If the script keeps failing, install manually:

### 1. Update System
```bash
sudo apt update && sudo apt upgrade -y
```

### 2. Setup Locale
```bash
sudo apt install locales -y
sudo locale-gen en_US en_US.UTF-8
sudo update-locale LC_ALL=en_US.UTF-8 LANG=en_US.UTF-8
export LANG=en_US.UTF-8
```

### 3. Add ROS2 Repository
```bash
sudo apt install software-properties-common -y
sudo add-apt-repository universe -y
sudo apt update
sudo apt install curl -y

sudo curl -sSL https://raw.githubusercontent.com/ros/rosdistro/master/ros.key \
  -o /usr/share/keyrings/ros-archive-keyring.gpg

echo "deb [arch=$(dpkg --print-architecture) signed-by=/usr/share/keyrings/ros-archive-keyring.gpg] http://packages.ros.org/ros2/ubuntu $(. /etc/os-release && echo $UBUNTU_CODENAME) main" | \
  sudo tee /etc/apt/sources.list.d/ros2.list > /dev/null

sudo apt update
```

### 4. Install ROS2 Kilted
```bash
sudo apt install ros-kilted-desktop -y
sudo apt install ros-dev-tools -y
sudo apt install python3-colcon-common-extensions -y
```

### 5. Install Gazebo
```bash
sudo apt install ros-kilted-ros-gz -y
```

### 6. Install Other ROS2 Packages
```bash
sudo apt install \
    ros-kilted-navigation2 \
    ros-kilted-nav2-bringup \
    ros-kilted-robot-localization \
    ros-kilted-vision-msgs \
    ros-kilted-image-transport \
    ros-kilted-cv-bridge \
    ros-kilted-rqt \
    ros-kilted-plotjuggler-ros \
    ros-kilted-laser-geometry \
    -y
```

### 7. Install Python Tools
```bash
sudo apt install python3-pip python3-venv -y
pip3 install --upgrade pip
pip3 install opencv-python opencv-contrib-python numpy scipy
pip3 install transforms3d ultralytics onnxruntime
```

### 8. Create Workspace
```bash
mkdir -p ~/teamsteelbot/klevor-v2/src
cd ~/teamsteelbot/klevor-v2
source /opt/ros/kilted/setup.bash
colcon build
```

### 9. Configure Environment
```bash
echo "" >> ~/.bashrc
echo "# Python virtual environment" >> ~/.bashrc
echo "source ~/teamsteelbot/klevor-v2/.venv/bin/activate" >> ~/.bashrc
echo "" >> ~/.bashrc
echo "# ROS2 Kilted Kaiju" >> ~/.bashrc
echo "source /opt/ros/kilted/setup.bash" >> ~/.bashrc
echo "source ~/teamsteelbot/klevor-v2/install/setup.bash" >> ~/.bashrc
echo "export ROS_DOMAIN_ID=42" >> ~/.bashrc
source ~/.bashrc
```

---

## Verification Commands

After installation, verify everything works:

```bash
# Check Ubuntu version
lsb_release -a
# Should show: Ubuntu 24.04 LTS

# Check ROS2
ros2 --version
# Should show: ros2 cli version: 0.33.0 or later

# Check Python
python3 --version
# Should show: Python 3.12.x

# Check pip
pip3 --version
# Should show: pip 24.x or later

# Check Gazebo
gz sim --versions
# Should show Gazebo Ionic

# Check YOLO26
yolo version
# Should show: Ultralytics YOLO 8.3.x

# List ROS2 packages
ros2 pkg list | head -20

# Test Gazebo
gz sim empty.sdf
# Should open Gazebo (Ctrl+C to close)
```

---

## If All Else Fails

### Option 1: Use Docker
```bash
# Install Docker
curl -fsSL https://get.docker.com -o get-docker.sh
sudo sh get-docker.sh

# Pull ROS2 Kilted image
docker pull osrf/ros:kilted-desktop

# Run container
docker run -it --rm \
  --network host \
  -v ~/teamsteelbot/klevor-v2:/root/teamsteelbot/klevor-v2 \
  osrf/ros:kilted-desktop
```

### Option 2: Use Humble Instead
If you can't upgrade to Ubuntu 24.04, use ROS2 Humble (on Ubuntu 22.04):

```bash
# Replace 'kilted' with 'humble' in all commands
sudo apt install ros-humble-desktop -y
```

**Note:** You'll lose the 10x EventsExecutor speedup, but YOLO26 will still work!

---

## Getting Help

If you're still stuck:

1. **Check logs:** Look for specific error messages
2. **Google the error:** Often someone else had the same issue
3. **ROS Answers:** https://answers.ros.org/
4. **ROS Discord:** https://discord.gg/ros

---

## Script Status

✅ **Script has been fixed** with:
- pip3 installation added
- Correct Gazebo package name
- Ubuntu 24.04 version check
- Virtual environment for Python packages (solves externally-managed-environment)
- Auto-activation in ~/.bashrc
- Better error messages

The updated script should work without these errors! 🎉

**Note:** The script now uses a Python virtual environment at `~/teamsteelbot/klevor-v2/.venv` which is automatically activated in your shell. This is the recommended approach for Ubuntu 24.04.

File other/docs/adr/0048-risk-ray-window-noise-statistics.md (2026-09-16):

# 0048. The forward lane corroborates a short return across adjacent rays

- Status: superseded by 0056
- Superseded by: 0056
- Date: 2026-09-13

## Context

The forward lane's short-return test originally took the bare minimum over the
sweep. That is an extreme-value statistic, not a clearance: with sigma = 0.03 m
of range noise across ~500 rays, the smallest reading in the lane sits 2-3
sigma below the nearest real surface, so a single noisy ray can read as an
obstacle that is not there. Setting the window to 1 restores that bare
minimum.

## Options considered

- (a) Keep the bare minimum over the forward lane.
- (b) Require several ADJACENT rays in the forward lane to corroborate the
      short return before it counts as an obstacle.

## Decision

(b). The window is a count of adjacent rays that must agree. A value of 1
restores the previous bare-minimum behaviour.

## Consequences

- A lone low return from range noise no longer reads as an obstacle, so the
  reactive clearance gate fires on corroborated geometry rather than on an
  extreme value of the noise distribution.
- The window is a ray count, not a distance: it trades sensitivity to a genuine
  narrow obstacle against false positives, and needs re-tuning if the LIDAR's
  ray count or noise changes.

## Superseded by 0056

Replaced by [0056](0056-raw-and-masked-scan.md): The scan is read twice, raw for speed
and masked for the escape.

The successor carries the current decision and its rationale; this file keeps
the original decision above so the supersede chain stays readable.

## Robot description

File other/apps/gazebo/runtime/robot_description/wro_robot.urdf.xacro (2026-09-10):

<?xml version="1.0"?>
<robot name="wro_robot" xmlns:xacro="http://www.ros.org/wiki/xacro">

  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
  <xacro:include filename="robot_properties.gen.xacro"/>

  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
  <xacro:property name="half_wheelbase" value="${wheelbase / 2}"/>
  <xacro:property name="half_track" value="${track_width / 2}"/>

  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
  <link name="base_link">
    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
    <inertial>
      <mass value="${chassis_mass}"/>
      <origin xyz="0 0 0" rpy="0 0 0"/>
      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
    </inertial>
  </link>

  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
  <link name="base_footprint"/>

  <joint name="base_footprint_joint" type="fixed">
    <parent link="base_footprint"/>
    <child link="base_link"/>
    <origin xyz="0 0 ${wheel_radius}" rpy="0 0 0"/>
  </joint>

  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
  <xacro:macro name="wheel_link" params="name">
    <link name="${name}">
      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
      <inertial>
        <mass value="${wheel_mass}"/>
        <origin xyz="0 0 0" rpy="${pi/2} 0 0"/>
        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
      </inertial>
    </link>
  </xacro:macro>

  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
  <xacro:macro name="steering_link" params="name">
    <link name="${name}">
      <inertial>
        <mass value="0.001"/>
        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
      </inertial>
    </link>
  </xacro:macro>

  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
  <xacro:steering_link name="front_left_steering"/>

  <joint name="front_left_steering_joint" type="revolute">
    <parent link="base_link"/>
    <child link="front_left_steering"/>
    <origin xyz="${half_wheelbase} ${half_track} 0" rpy="0 0 0"/>
    <axis xyz="0 0 1"/>
    <limit lower="${-max_steering_angle}" upper="${max_steering_angle}" effort="10" velocity="3.0"/>
  </joint>

  <xacro:wheel_link name="front_left_wheel"/>

  <joint name="front_left_wheel_joint" type="continuous">
    <parent link="front_left_steering"/>
    <child link="front_left_wheel"/>
    <origin xyz="0 0 0" rpy="0 0 0"/>
    <axis xyz="0 1 0"/>
  </joint>

  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
  <xacro:steering_link name="front_right_steering"/>

  <joint name="front_right_steering_joint" type="revolute">
    <parent link="base_link"/>
    <child link="front_right_steering"/>
    <origin xyz="${half_wheelbase} ${-half_track} 0" rpy="0 0 0"/>
    <axis xyz="0 0 1"/>
    <limit lower="${-max_steering_angle}" upper="${max_steering_angle}" effort="10" velocity="3.0"/>
  </joint>

  <xacro:wheel_link name="front_right_wheel"/>

  <joint name="front_right_wheel_joint" type="continuous">
    <parent link="front_right_steering"/>
    <child link="front_right_wheel"/>
    <origin xyz="0 0 0" rpy="0 0 0"/>
    <axis xyz="0 1 0"/>
  </joint>

  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

  <xacro:macro name="rear_steering_assembly" params="side y_sign">
    <xacro:steering_link name="rear_${side}_steering"/>

    <joint name="rear_${side}_steering_joint" type="revolute">
      <parent link="base_link"/>
      <child link="rear_${side}_steering"/>
      <origin xyz="${-half_wheelbase} ${y_sign * half_track} 0" rpy="0 0 0"/>
      <axis xyz="0 0 1"/>
      <limit lower="${-max_steering_angle}" upper="${max_steering_angle}" effort="10" velocity="3.0"/>
      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
      <mimic joint="front_${side}_steering_joint" multiplier="${-rear_steer_ratio}" offset="0"/>
    </joint>

    <xacro:wheel_link name="rear_${side}_wheel"/>

    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
    <joint name="rear_${side}_wheel_joint" type="continuous">
      <parent link="rear_${side}_steering"/>
      <child link="rear_${side}_wheel"/>
      <origin xyz="0 0 0" rpy="0 0 0"/>
      <axis xyz="0 1 0"/>
    </joint>
  </xacro:macro>

  <xacro:rear_steering_assembly side="left" y_sign="1"/>
  <xacro:rear_steering_assembly side="right" y_sign="-1"/>

  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
  <link name="camera_link">
    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
    <inertial>
      <mass value="0.005"/>
      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
    </inertial>
  </link>

  <joint name="camera_joint" type="fixed">
    <parent link="base_link"/>
    <child link="camera_link"/>
    <origin xyz="${camera_mount_x} 0 ${camera_mount_z}" rpy="0 ${camera_mount_pitch} 0"/>
  </joint>

  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
  <link name="lidar_link">
    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
    <inertial>
      <mass value="0.110"/>
      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
    </inertial>
  </link>

  <joint name="lidar_joint" type="fixed">
    <parent link="base_link"/>
    <child link="lidar_link"/>
    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
    <origin xyz="${lidar_mount_x} 0 ${chassis_height + lidar_mount_z}" rpy="0 0 0"/>
  </joint>

  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
  <link name="imu_link">
    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
    <inertial>
      <mass value="0.0025"/>
      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
    </inertial>
  </link>

  <joint name="imu_joint" type="fixed">
    <parent link="base_link"/>
    <child link="imu_link"/>
    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
    <origin xyz="0 0 ${imu_mount_z}" rpy="0 0 0"/>
  </joint>

  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

</robot>

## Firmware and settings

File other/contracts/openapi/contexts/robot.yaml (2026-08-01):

openapi: 3.0.0
info:
  title: vTitan Robot API
  version: 1.0.0
  description: |
    Robot context — responsible for robot lifecycle management, fleet
    coordination, configuration, and real-time status reporting.

servers:
  - url: http://localhost:8010
    description: Local development

security:
  - bearerAuth: []

paths:
  /v1/robots:
    get:
      summary: List all registered robots
      operationId: listRobots
      tags:
        - Robot
      parameters:
        - name: fleet_id
          in: query
          schema:
            type: string
            format: uuid
          description: Filter by fleet
        - name: state
          in: query
          schema:
            $ref: '#/components/schemas/RobotState'
      responses:
        '200':
          description: Array of robots
          content:
            application/json:
              schema:
                type: array
                items:
                  $ref: '#/components/schemas/Robot'
    post:
      summary: Register a new robot
      operationId: createRobot
      tags:
        - Robot
      requestBody:
        required: true
        content:
          application/json:
            schema:
              $ref: '#/components/schemas/CreateRobotRequest'
      responses:
        '201':
          description: Robot registered
          content:
            application/json:
              schema:
                $ref: '#/components/schemas/Robot'
        '422':
          $ref: '#/components/responses/ValidationError'

  /v1/robots/{robotId}:
    get:
      summary: Get robot details
      operationId: getRobot
      tags:
        - Robot
      parameters:
        - name: robotId
          in: path
          required: true
          schema:
            type: string
            format: uuid
      responses:
        '200':
          description: Robot details
          content:
            application/json:
              schema:
                $ref: '#/components/schemas/Robot'
        '404':
          $ref: '#/components/responses/NotFound'
    patch:
      summary: Update robot metadata
      operationId: updateRobot
      tags:
        - Robot
      parameters:
        - name: robotId
          in: path
          required: true
          schema:
            type: string
            format: uuid
      requestBody:
        required: true
        content:
          application/json:
            schema:
              $ref: '#/components/schemas/UpdateRobotRequest'
      responses:
        '200':
          description: Robot updated
          content:
            application/json:
              schema:
                $ref: '#/components/schemas/Robot'
        '404':
          $ref: '#/components/responses/NotFound'
        '422':
          $ref: '#/components/responses/ValidationError'
    delete:
      summary: Delete a robot
      operationId: deleteRobot
      tags:
        - Robot
      parameters:
        - name: robotId
          in: path
          required: true
          schema:
            type: string
            format: uuid
      responses:
        '204':
          description: Robot deleted
        '404':
          $ref: '#/components/responses/NotFound'

  /v1/robots/{robotId}/status:
    get:
      summary: Get robot real-time status
      operationId: getRobotStatus
      tags:
        - Robot
      parameters:
        - name: robotId
          in: path
          required: true
          schema:
            type: string
            format: uuid
      responses:
        '200':
          description: Current robot status
          content:
            application/json:
              schema:
                $ref: '#/components/schemas/RobotStatus'
        '404':
          $ref: '#/components/responses/NotFound'
        '503':
          description: Robot offline
          content:
            application/json:
              schema:
                $ref: '#/components/schemas/ErrorResponse'

  /v1/robots/{robotId}/config:
    put:
      summary: Update robot configuration
      operationId: updateRobotConfig
      tags:
        - Robot
      parameters:
        - name: robotId
          in: path
          required: true
          schema:
            type: string
            format: uuid
      requestBody:
        required: true
        content:
          application/json:
            schema:
              $ref: '#/components/schemas/UpdateRobotConfigRequest'
      responses:
        '200':
          description: Configuration updated
          content:
            application/json:
              schema:
                $ref: '#/components/schemas/RobotConfig'
        '404':
          $ref: '#/components/responses/NotFound'
        '422':
          $ref: '#/components/responses/ValidationError'
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

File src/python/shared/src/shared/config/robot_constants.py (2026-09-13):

"""Hand-written wrapper over the generated ``RobotConfig`` DTO.

The DTO (``shared.config.generated.robot_schema``) is generated from
``src/config/schemas/robot.schema.json`` and holds only the TOML's fields and
their descriptions -- all optional, because a hardware-profile overlay declares
only the keys it changes. Everything with behavior lives here: the
``steering_limit_deg`` validator, the derived helpers (``linkage_ratio``,
``max_steering_angle``), the profile merge, and the check that a hardware
profile actually supplied the motor and servo facts.

Kept behind the same public names the codebase already imports, so the split
between generated DTO and hand-written wrapper is invisible to callers.
"""

from __future__ import annotations

import math
from typing import TYPE_CHECKING, ClassVar

from pydantic import ValidationInfo, field_validator

from shared.config.generated.robot_schema import (
    Ackermann,
    Camera,
    Chassis,
    Drivetrain,
    Imu,
    Lidar,
    RobotConfig as _RobotConfigDTO,
    Steering as _SteeringDTO,
    Wheel,
)
from shared.config.hardware_profile import PROFILES_ROOT, active_profiles
from shared.config.paths import SHARED_CONFIG_ROOT, load_toml_merged, profile_overlay_paths

if TYPE_CHECKING:
    from pathlib import Path

__all__ = [
    "Ackermann",
    "Camera",
    "Chassis",
    "Drivetrain",
    "Imu",
    "Lidar",
    "RobotConstants",
    "Steering",
    "Wheel",
]

DEFAULT_CONFIG_PATH: Path = SHARED_CONFIG_ROOT / "robot.toml"
"""src/config/robot.toml -- resolved via shared.config.paths rather
than a fragile ``parents[N]`` relative to this file."""


class Steering(_SteeringDTO):
    """Servo travel, the road-wheel angle it produces, and how much of it we use.

    Two different numbers, deliberately separate since 2026-08-21:

    * ``max_wheel_angle_deg`` is PHYSICS -- what the linkage actually delivers at
      full servo lock, measured with a protractor. It is the only input to
      ``linkage_ratio``, so it must never be lowered to mean "steer more gently".
    * ``steering_limit_deg`` is POLICY -- how much of that travel the navigator
      is allowed to command. Lower it freely.

    They were one field until a 270 deg servo made the distinction load-bearing.
    With the 180 deg servo the two coincided at 55 deg, so nothing distinguished
    them; conflated, capping the command to 55 on an 85 deg linkage would have
    recomputed ``linkage_ratio`` as 55/135 = 0.407 instead of the true
    85/135 = 0.630, and ``ackermann_motor_node`` -- the one consumer that
    converts a wheel angle back to a servo angle -- would have driven the servo
    1.55x too far. The wheels would reach 85 deg when 55 was asked for.

    The simulator would NOT have caught it: it reads ``max_steering_angle``
    directly and never performs the servo conversion, so the error is invisible
    in every sweep and appears only on hardware.
    """

    @field_validator("steering_limit_deg")
    @classmethod
    def _limit_within_linkage(cls, value: float | None, info: ValidationInfo) -> float | None:
        """Reject a commanded limit the linkage cannot reach.

        Silently clamping would hide a real config error: a limit above the
        physical maximum means somebody believes the car steers harder than it
        does, and every downstream angle would be quietly wrong.
        """
        physical = info.data.get("max_wheel_angle_deg")
        if value is None or physical is None:
            return value
        if value <= 0:
            msg = f"steering_limit_deg must be positive, got {value}"
            raise ValueError(msg)
        if value > physical:
            msg = (
                f"steering_limit_deg ({value}) exceeds the linkage's "
                f"max_wheel_angle_deg ({physical}) -- the hardware cannot reach it"
            )
            raise ValueError(msg)
        return value

    @property
    def linkage_ratio(self) -> float:
        """Road-wheel degrees produced per servo degree.

        Derived from the bench-measured ``max_wheel_angle_deg``, not declared
        directly -- kept for consumers that convert an arbitrary wheel angle
        to a servo angle (e.g. ``ackermann_motor_node``).

        Deliberately independent of ``steering_limit_deg``: the gearing does not
        change because we chose to use less of it.
        """
        return self.max_wheel_angle_deg / self.servo_max_angle_deg

    @property
    def max_steering_angle(self) -> float:
        """Largest road-wheel angle the navigator may command (radians).

        ``steering_limit_deg`` when set, otherwise the linkage's full travel.
        This is the value the planner and simulator gate on.
        """
        return math.radians(self.steering_limit_deg or self.max_wheel_angle_deg)


_COMPONENT_FACTS: tuple[tuple[str, str, str], ...] = (
    ("drivetrain", "max_speed_mps", "a drive motor"),
    ("drivetrain", "max_accel_mps2", "a drive motor"),
    ("drivetrain", "speed_response_tau_s", "a drive motor"),
    ("steering", "servo_max_angle_deg", "a steering servo"),
    ("steering", "max_wheel_angle_deg", "a steering servo"),
)
"""Keys the base config refuses to guess, and the component that supplies each.

The base ``robot.toml`` describes the chassis, which does not change when a
motor or servo is swapped. These all do change, so requiring them from a
named profile is what stops a run from silently modelling whichever hardware
happened to be checked in -- the failure mode that put a night of motor tests
on the wrong ceiling, undetectable from behaviour alone."""
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

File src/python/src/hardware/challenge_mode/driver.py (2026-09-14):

"""GPIO driver for the challenge-mode jumper (GPIO23 shorted to GND vs. floating high)."""

import logging

from gpiozero import InputDevice

from src.hardware.challenge_mode.config import Config
from src.logger import configure_json_logging
from src.logger.constants import DETAILS_KEY

configure_json_logging()


class Driver:
    """Reads the challenge-mode jumper via the internal pull-up, no external resistor.

    Shorted to GND (LOW) -- Obstacle Challenge. Absent, pulled up internally (HIGH) --
    Open Challenge. Unlike the button driver this exposes single instantaneous reads only:
    the jumper is a static wire link, not a momentary control, so there's no
    debounce/long-press state to track. Sampling the read several times to confirm it's
    stable before trusting it is the caller's responsibility -- see state_machine_node's
    boot-check loop, which needs non-blocking per-tick reads rather than a driver-internal
    sleep loop.
    """

    def __init__(self, config: Config | None = None) -> None:
        self.config: Config = config or Config.load()
        self._input: InputDevice | None = None
        self.logger: logging.Logger = logging.getLogger(__name__)

    def connect(self) -> None:
        """Initialize GPIO with the internal pull-up enabled."""
        self.logger.info(
            "Connecting to challenge-mode jumper",
            extra={DETAILS_KEY: {"gpio_pin": self.config.challenge_mode_gpio_pin}},
        )
        self._input = InputDevice(self.config.challenge_mode_gpio_pin, pull_up=True)
        self.logger.info("Challenge-mode jumper connected successfully")

    def is_jumper_inserted(self) -> bool:
        """True if the jumper is shorting the pin to GND (Obstacle Challenge)."""
        if self._input is None:
            self.connect()
        assert self._input is not None
        return bool(self._input.is_active)

    def close(self) -> None:
        """Clean up GPIO resources."""
        if self._input is not None:
            self._input.close()
            self._input = None

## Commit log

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2026-07-31 feat(auto-annotator): resolve codebase audit, add goose migrations, update OpenAPI, and enforce gRPC protovalidate
    Complete all items from the auto-annotator codebase audit across backend Go services,
    Python ML services, frontend components, and proto definitions.
    - Persistence & Migrations:
    - Migrate single-file `schema.sql` setup to `goose` versioned migration system under `api/db/migrations/`
    - Consolidate sqlc codegen and application bootstrap around unified `00001_init.sql` schema
    - Add `Migrate(sqlDB)` helper in `api/db/migrate.go` and wire into `domain/store/store.go`
    - Add `db:migrate:new` and `db:migrate:status` Taskfile targets using embedded migration assets
    - API, OpenA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
    [config.py]
2026-08-01 test(backend, robot): add telemetry integration tests, expand robot node test coverage, and improve gRPC error propagation
    Add comprehensive backend integration tests, expand unit test coverage across key ROS2 nodes,
    and refine gRPC error propagation across streaming endpoints.
    - Backend Integration Testing & Error Handling:
    - Add end-to-end integration test scenarios in `platform/backend/cmd/server/integration_test.go`
    covering mid-stream invalid snapshots, concurrent client streaming, session persistence
    round-trips, and WebSocket broadcast functionality
    - Introduce `wrapRecvErr` helper in `internal/ingest/server.go` to preserve upstream gRPC status
    codes (e.g. `InvalidArg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
    [robot.yaml]
2026-08-01 fix(ansible): relocate group_vars next to inventory for auto-discovery
    Cause: ansible/group_vars/ lived at the project root, but Ansible only
    auto-loads group_vars/host_vars from directories adjacent to the inventory
    file or the playbook file. Neither matched, so ansible_user and every other
    shared var (repo_dir, old_repo_dir, pixi_bin, etc.) silently resolved as
    undefined on the first real provisioning run against the Pi 5, failing at
    the "Add {{ ansible_user }} to hardware groups" task.
    Key Changes:
    - git mv ansible/group_vars -> ansible/inventory/group_vars (all.yml,
    robot_pi5.yml, robot_pi_zero.yml), matching Ansible's inventory-relative
    auto-discovery path
    - Update ansible/README.m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
    [robot_pi5.yml, robot_pi_zero.yml]
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2026-08-01 refactor(config): give the mat, the robot and the tuning one source each
    The mat's geometry was maintained twice by hand -- once in the Python classes
    of shared/config/constants.py, once in the Go const blocks of
    simconfig/constants.go, whose header asked future editors to keep the two in
    sync themselves. Around forty tuning values had the same shape: a literal in
    the module beside a comment naming the config field it duplicated.
    That arrangement had already failed, quietly, in three places. The sign
    router's DEFORM_DEPTH_BUFFER_M sat in its TOML with no reader at all while a
    duplicate literal did the work. tests/test_constants.py carried
    SIGN_ACTIVATION_DIST 0.80 and SIGN_PASSED_DIST 1.20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
    [robot_properties.gen.xacro]
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2026-08-01 fix(robot): derive the steering limit instead of stating it in four places
    The road-wheel angle at full lock was written down four times, and three of
    them disagreed.
    motors.toml had the two measured facts: the servo reaches 90 degrees of travel
    and the linkage produces 0.78 road-wheel degrees per servo degree. robot.toml
    had their product, 1.2253 rad, computed by hand, under a comment saying the
    factors lived in .env.example -- which by then said to see motors.toml. And the
    code defaults said something else entirely: MotorSteeringConfig defaulted to 45
    degrees at a 1.0 ratio, which is not this chassis but a direct-drive one with
    half the travel, while WaypointController defaulted to 0.5236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
    [robot_properties.gen.xacro]
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2026-08-01 feat(robot): stop on the press, not on the release, and add a hold-to-power-off
    Two changes to the only physical control the operator has.
    The E-STOP was classified on release. Holding the button did nothing until you
    let go, which is backwards for the one control whose job is to stop a moving
    robot -- the instinct in an emergency is to grip it and keep gripping, and the
    robot kept driving for exactly as long as the operator did. Hold events now fire
    from a timer while the button is still down, and release only reports a short
    press if no threshold was ever crossed.
    Holding past 10s now powers both boards down cleanly. The only safe shutdown
    until now needed a laptop, a network and SSH, no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
    [config.py, driver.py]
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2026-08-02 fix(nav): TIER 3.2-3.3 — state_machine/types.py enum swaps
    3.2 RaceStatus.current_corridor: str → Section | None
    - Was empty string for unknown; now uses None
    - Values: Section.NORTH, SOUTH, EAST, WEST
    3.3 LidarMetrics.path_status: str → PathStatus enum
    - Created new PathStatus(StrEnum) with: CLEAR, BLOCKED, NARROW
    - Replaces magic string literals
    TIER 3: Use existing or new enums instead of str
    [types.py]
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2026-08-02 fix(nav): TIER 5.2-5.3 — consolidate steering speed and lap count constants
    5.2 Steering speed 20:
    - motors/base.py: DEFAULT_STEERING_SPEED = 20 (single source)
    - motors/config.py: centering_speed now references DEFAULT_STEERING_SPEED
    - motors/build_hat/driver.py: annotated hardcoded defaults with comment
    5.3 Lap count 3:
    - core_navigator.py: num_laps default → CompetitionSpecs.OPEN_CHALLENGE_LAPS
    - track_navigator_node.py: num_laps default → CompetitionSpecs.OPEN_CHALLENGE_LAPS
    - launch_settings.py: laps default → CompetitionSpecs.OPEN_CHALLENGE_LAPS
    - Single source of truth for competition rule (3 laps for open challenge)
    TIER 5: Eliminate duplicated string constant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
    [config.py, driver.py]
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2026-08-02 fix(config): move hardcoded constants to config files
    Move constants from Python code to config files for true configuration management:
    5.2 Steering speed (20 deg/s):
    - Removed DEFAULT_STEERING_SPEED from motors/base.py
    - Already defined in motors/motors.toml:steering.centering_speed
    - config.py now references toml value with explanatory comment
    5.4 Serial port fallback (/dev/ttyACM0):
    - Removed hardcoded DEFAULT_SERIAL_PORT from uart_rvc.py
    - Added default_port field to IMU config toml files:
    * bno08x_uart_rvc.toml
    * bno08x_mcp2221_uart_rvc.toml
    - Code now reads config.default_port (set from toml) instead of hardcode
    All tuning/configuration now sources from TOML/env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
    [config.py]
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2026-08-03 refactor: use DETAILS_KEY constant instead of hardcoded 'details' string
    Replaced ~23 hardcoded 'details' strings with DETAILS_KEY constant from
    logger/constants.py across 12 files in hardware and navigation modules.
    Single source of truth for the log key name; prevents accidental typos.
    [driver.py]
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2026-08-04 fix(nav): correct the heading estimate when blind direction inference overturns the assumption
    assumed_start_conditions pairs a starting yaw with whichever direction was
    assumed at construction -- CW and CCW yaw values differ by exactly pi for
    the same section, since TRAVEL_DIRS' two vectors are exact opposites. Real
    races are blind (no metadata, direction unknown until inferred from LIDAR
    mid-drive), and TrackNavigator's --direction CLI arg defaults to "cw", so
    every race starts by assuming clockwise regardless of the round's actual
    direction.
    DirectionEstimator correctly infers the true direction later, and
    _commit_direction() updates self._direction and rebuilds the waypoint path
    to matc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
    [estimator.py]
2026-08-04 fix(nav): re-seed position estimate on reset(), not just heading
    reset() runs at every FINISHED -> RACING transition (the state machine
    cycles this purely from the button, with no process restart) and already
    re-zeroed the heading reference, but never re-seeded position. Confirmed
    on real hardware across two consecutive races the same session
    (run_20260804_143942, run_20260804_144019): pose_x/pose_y reached the
    hundreds of metres on a track no larger than 3m square, and the second
    race's first logged tick continued directly from where the first race's
    last tick left off (-98.4,-100.1 -> -125.4,-127.1) instead of resetting.
    Confirmed not a parsing artifact or a bug in the localizer's own mat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
    [estimator.py]
2026-08-04 fix(nav): reset_heading_reference also clears _yaw_correction
    Second half of the position-carryover bug fixed earlier today, in a field
    that fix missed. apply_yaw_correction (added the same day, for when blind
    direction inference overturns the direction assumed at construction)
    writes a full, up-to-pi jump to StateEstimator._yaw_correction. But
    reset_heading_reference() -- called by TrackNavigator.reset() at every
    race start -- only cleared _imu_yaw_offset/_relative_imu_yaw, not
    _yaw_correction, so a direction-reassumption correction from one race
    silently survived into the next.
    Confirmed on real hardware: a CW race immediately following a CCW one
    (same process, button-reset between them,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
    [estimator.py]
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2026-08-08 refactor(config): Phase 4B - decouple tuning from module-level freezing
    Remove NavigationTuning.load_default() from module level in 8 files (tests + src),
    enabling parallelization and test-time tuning injection. Replace with dataclass
    factories (test_constants, parking, wall_heading) or __init__ parameters (kinematics,
    simulated_hardware_gateway, state_machine/estimator).
    - test_constants.py: TuningDerivedConstants dataclass factory + conftest fixtures
    - test_sign_router.py: router_config fixture, tuning-derived SignRouterConfig
    - parking.py: _ParkingConstants dataclass, optional tuning in __init__
    - wall_heading.py: _WallHeadingConstants dataclass, lazy evaluation
    - kinematics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
    [estimator.py]
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2026-08-08 refactor(config): Phase 4C - eliminate module-level constants via context classes
    Converted four files to use context-based tuning constants instead of
    module-level constants:
    1. wall_heading.py: WallHeadingContext with _WallHeadingConstants
    - estimate_yaw_from_walls() now accepts optional context parameter
    - All undefined constant references fixed
    2. kinematics.py: KinematicsContext with _KinematicsConstants
    - AckermannKinematics.__init__() uses context for defaults
    - Defaults: max_steer_rate, max_accel, max_speed_mps, rear_steer_ratio
    3. simulated_hardware_gateway.py: SimulatorContext with _SimulatorConstants
    - SimulatedHardwareGateway.__init__() and advance() use context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
    [estimator.py]
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2026-08-08 fix(nav,sim): repair runtime crashes left by the context-class refactor
    Phase 4C moved tuning-derived constants into context classes but left call
    sites referencing the old module-level names. Those are `NameError`s at call
    time, not import time, so `check_imports.py` cannot see them -- `ruff
    --select F821` found them.
    `parking.py` is the serious one: `_WALL_STANDOFF` and `_MARKER_STANDOFF` are
    gone, and the five references left behind are in the wall and marker collision
    guards. Production robot code, guaranteed to crash the moment a parking
    approach checks its footprint.
    `ScenarioSimulator.__init__` read `self._tuning` fifteen lines before
    assigning it.
    Separately, `NavigationTun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
    [estimator.py]
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2026-08-08 fix(nav,sim): kill import-time tuning freezes, consolidate load_default() call sites
    Two module-level NavigationTuning.load_default() calls froze tuning at import
    time, silently ignoring --tuning: navigation/utils.py (dead, now deleted) and
    vision_emulator.py's _DETECTION_CONFIDENCE (now threaded through as a param
    from the gateway's own tuning). Also collapses the 31 remaining
    tuning-or-load_default()/if-tuning-is-None sites across 17 files into a single
    src/config/tuning_helpers.get_tuning() call, and moves _dist2d out of
    sign_discovery.py into navigation/utils.py alongside the other shared
    geometry helpers, where sign_router now imports it from directly.
    [estimator.py]
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2026-08-08 refactor(shared,simgen): load track/robot physical constants from TOML at runtime
    track_constants_gen.py and robot_constants_gen.py were Go-generated Python
    checked into VCS, imported by exactly two files (constants.py,
    starting_zone.py) and nothing else -- everything downstream already went
    through the TrackDimensions/RobotSpecs wrapper classes. That generated file
    was a third copy of every measurement (TOML, Go, Python) that could drift out
    of sync, the same problem NavigationTuning already solved for tuning
    parameters by reading its TOML tree directly at runtime.
    Adds TrackConstants/RobotConstants pydantic models that read track.toml/
    robot.toml themselves -- no codegen step, no generate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
    [robot_constants.py]
2026-08-08 refactor(shared): remove shared.config.enums shim, make StartingConditions honest about unknowns
    shared.config.enums was a pure re-export of shared.domain.enums, kept only so
    existing importers didn't have to change when RiskLevel (and later the rest)
    moved to be StrEnum-based in domain.enums. It added an indirection with no
    remaining purpose; every one of its 58 importers now imports
    shared.domain.enums directly.
    Also fixes StartingConditions.direction/section defaulting to
    COUNTERCLOCKWISE/SOUTH: a blind run only knows its pose relative to its own
    start, not the track's absolute compass labels, until direction/corridor
    inference resolves them -- a default naming a specific value let metad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
    [types.py]
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2026-08-08 refactor(robot): extract geometry helpers, add TuningContext base class
    Move sign_router's chassis half-diagonal/behind-tolerance constants into
    named functions in src/navigation/geometry.py, giving them a home outside
    the routing module that doesn't otherwise own chassis geometry.
    Factor the repeated tuning/constants __init__ wiring shared by
    EstimatorContext, WallHeadingContext, SignRouterContext, KinematicsContext,
    SimulatorContext, and ParkingContext into a generic TuningContext base in
    src/config/tuning_helpers.py; each subclass now just sets _constants_cls.
    [estimator.py]
2026-08-08 refactor(robot,shared): modernize dataclasses, drop dead TypeVar, PEP 604 isinstance
    Add slots=True to plain-field dataclasses across state_machine/types.py,
    hardware/{display,camera,imu}/base.py, sign_discovery, parking, collision
    avoidance, and NavigationTuning -- smaller instances, faster attribute
    access, no field/property conflicts in any of them.
    LogPayload's custom __init__ relied on the plain-dataclass class-attribute
    fallback to leave details/exc_info as None when not set; slots removes
    that fallback (unset slots raise AttributeError instead), so the __init__
    now sets both explicitly before the conditional overrides.
    Also: remove an unused module-level TypeVar in shared/io/jsonl.p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
    [types.py]
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2026-08-08 style(shared): resolve ruff lint violations and modernize typing
    Manually fix remaining ruff findings that --fix cannot resolve:
    - Sort __all__ and expand quaternion_to_yaw arg docstring
    - Switch dataclass defaults to field(default_factory=...)
    - Use Path.open(), assign exception messages to vars, prefer TypeError
    - Fix docstring blank-line/missing-docstring (D) rules and commented-out code
    - Add domain/__init__.py to satisfy INP001
    - Replace Any with object, drop unused arg, type jsonl _file as TextIOWrapper
    [robot_constants.py]
2026-08-08 style(robot): ruff-fix auto-fixable lint findings
    Apply ruff --fix across robot (import sorting, unused noqa removal,
    pytest fixture/mark parenthesization, yoda-conditions, deprecated imports).
    Manual review of remaining non-fixable findings is pending.
    [driver.py]
2026-08-08 style(robot): resolve manual ruff lint findings across src, ros2_ws, scripts, tests
    Finish the lint sweep begun in the auto-fix commit: address the remaining
    findings that need human judgement.
    - src/navigation: fix D205 docstring layouts; drop unused F401 imports;
    hoist lazy PLC0415 imports where there is no circular-import risk
    (sign_router, start_conditions, track_geometry, ros2_hardware_gateway);
    extract the localization speed-bound guard into _reject_implausible_speed
    (C901); scope noqa for complex constructors/loop (scenario_simulator,
    track_navigator_node) and justify S101 invariant asserts.
    - src/state_machine: remove stale RaceMetrics from types.__all__ (it lives in
    rac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
    [driver.py, estimator.py, types.py]
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2026-08-08 fix(hardware): dedupe remaining hardware-constant drift risks
    Three items flagged by the earlier ROS2 constants audit as still open:
    - SERIAL_TIMEOUT/DATA_LOCK_TIMEOUT in bno08x/uart_rvc.py were raw module
    constants sitting alongside an existing pydantic Config class that already
    has a checked-in TOML for exactly this purpose -- same shape as the
    turning_speed bug fixed earlier today. Moved both into Config as fields.
    bno08x/mcp2221/uart_rvc.py imported the same module constant for its own
    connect() override; updated to read self.config.serial_timeout (falls
    back to the base UARTRVCConfig's default, unchanged behavior).
    - servo/driver.py and dc_encoder/driver.py each independent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
    [driver.py]
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2026-08-10 fix(shared): declare bench-measured max_wheel_angle_deg instead of a stale linkage_ratio
    Cause: robot.toml's [steering] linkage_ratio = 0.78 (90 deg servo -> ~70.2
    deg wheel) was never re-measured after the linkage geometry changed and had
    drifted. A 2026-08-09 bag analysis found a ~1.8x global under-turn on
    hardware and flagged linkage_ratio as one of two untested candidates,
    recommending a bench measurement with a protractor instead of guessing from
    bag data. Done 2026-08-10: with the servo at its true 90 deg end-stop
    (confirmed not stalling early), the front wheel reaches only ~55 deg.
    A bare ratio is also awkward to re-measure and re-declare by hand each time
    the linkage or servo change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
    [robot_properties.gen.xacro]
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2026-08-10 refactor(robot,ansible): split provisioning scripts into their own dir, tag ansible phases
    Cause: platform/robot/scripts/ mixed deploy/audit/watchdog scripts in with
    diagnostic tooling (bag/, hardware/, common/, sim/), with no way to run just
    one phase of an ansible provisioning pass.
    - Moved the 12 provisioning/ops scripts (audit-*, boot-check-watchdog,
    usb-link-watchdog, wait-for-gadget-link, bootstrap-fresh-zero, deploy-*,
    safe-shutdown-*, verify-zero-integration, _ssh_preflight) into
    scripts/provisioning/. Fixed each moved script's ROBOT_DIR calculation
    for the extra directory level, and every reference across the 3 live
    systemd units, both Taskfiles, pixi.toml, a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
    [driver.py]
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2026-08-12 docs(rename): finish the voldemorbot -> vtitan stale-reference cleanup
    Leftover pre-rename strings survived the org/repo rename (teamvoldemor/
    voldemorbot -> teamvoltimor/vtitan) in comments, docstrings, an ansible
    default, and a shell audit's directory list -- confusing anyone reading
    them post-migration, since the actual checkout, worktrees, and services
    have all been vtitan-named since 2026-07-29/30. Pure text fixes, no
    behavior change.
    [robot_pi5.yml, robot_pi_zero.yml]
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2026-08-12 refactor(navigation): unify angle-wrap + LidarLocalizer construction
    Cause: 2026-08-11 duplication audit found 3 near-identical angle-wrap
    implementations and 4 hand-spelled LidarLocalizer constructor calls,
    any one of which could silently drift from the others.
    - Promote src.navigation.utils._wrap to a public wrap_angle; every
    other module-private wrap (track_geometry._wrap_angle's modulo form,
    estimator.wrap_angle's math.remainder form) now imports it instead
    of re-implementing it.
    - Add navigation.localization.make_localizer(walls, LocalizationParams)
    and use it at all 4 sites in the sim and ROS2 hardware gateways that
    previously repeated the same 7-arg LidarLocali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
    [estimator.py]
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2026-08-12 feat(vision): add camera detection-tuning controls, fix Hailo NPU letterbox
    Cause: RPi Camera Module 3 driver only pinned AnalogueGain and FrameRate,
    leaving focus/exposure/AWB/noise-reduction on libcamera defaults with no
    way to tune them for the WRO venue's controlled white artificial light
    (or natural light for practice) without editing code. Separately, the
    Hailo detector's cv2.resize() stretched the 16:9 camera frame directly to
    the HEF's square 640x640 input, distorting every sign's proportions --
    the compiled gmr.hef was calibrated, quantized and its mAP measured
    against letterboxed (aspect-preserving, padded) input the whole way
    through hailo/src/image.py and hailo/eval/metrics.py, a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
    [driver.py]
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2026-08-12 refactor(hardware,navigation): dedup gateway protocol, camera config, IMU/button defaults
    Cause: 2026-08-11 duplication audit's medium-ROI items #7-11.
    - navigation/ports.py: HardwareGateway Protocol extended with
    set_believed_walls, reset_position, reset_heading_reference,
    correct_heading_for_direction_change. Only set_believed_walls was
    actually implemented by both gateways before this; the other three
    existed only on ROS2HardwareGateway (race-restart / direction-inference
    correction flows track_navigator_node.py uses), so
    SimulatedHardwareGateway gained implementations delegating to its
    StateEstimator to keep satisfying the Protocol CoreNavigator is typed
    aga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
    [config.py, driver.py]
2026-08-13 refactor(hardware,simulation): extract shared drivers, streamer, split god-modules
    Cause: 2026-08-11 duplication audit's largest-line-win items #12-15.
    - hardware/imu/bno08x/i2c_base.py (new): BNO08xI2CDriver base absorbing
    the lazy-connect property, enable_sensors, all 6 sensor getters, and
    get_calibration_status shared verbatim between the direct-I2C and
    MCP2221-bridge drivers. connect()/close() stay per-subclass (real
    lock/error-handling differences). Along the way: the direct-I2C driver
    was silently missing get_all_data() (an abstract method it never
    overrode) -- now inherited and fixed. Standardized both drivers'
    not-connected getter behavior on the safer exp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
    [driver.py]
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2026-08-14 refactor(robot): drive hardcoded constants and topics through config
    Consolidate scattered hardcoded values into their config models per the
    2026-08-13 hardcoded-config-values audit.
    - Route topics through RosTopicConfig everywhere (nodes + diagnostic scripts);
    add sensors.joy/camera_image_raw and a simulation group.
    - Move LIDAR baud/scan_mode/angle_compensate and respawn delays/vision
    backend into config/launch/*.toml via LaunchSettings; share TF frame names
    via a new TfFrames constant.
    - Replace JSON wire-format dicts with pydantic models (wire_models.py) for
    /race_metrics, /ui/telemetry_summary and /button/hold.
    - Fold motor calibration (encoder PID/counts, servo PWM, IMU timeou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
    [config.py, driver.py]
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2026-08-20 fix(robot): use resolved counts_per_rev for the dc_encoder speed estimator
    SpeedEstimator was built from the raw counts_per_rev constructor arg
    instead of self._counts_per_rev, so any caller relying on the
    DcMotorPwmConfig default (ackermann_motor_node's driver factory always
    does) passed None through and crashed on_configure() with a TypeError
    that rclpy's lifecycle machinery swallowed silently.
    [driver.py]
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
